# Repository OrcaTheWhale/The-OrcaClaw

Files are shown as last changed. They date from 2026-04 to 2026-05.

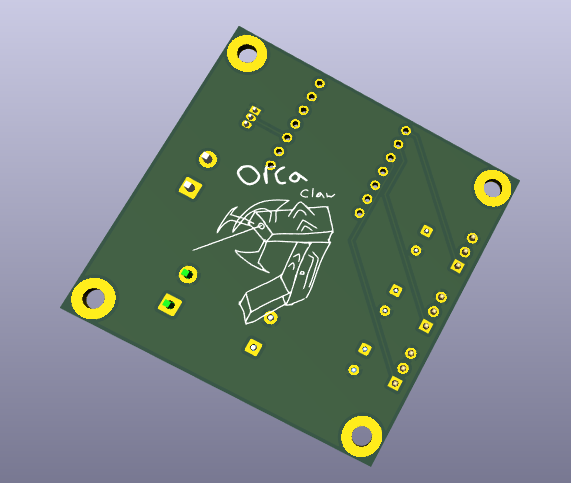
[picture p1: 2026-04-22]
assets/OrcaClawPCBBottom.png

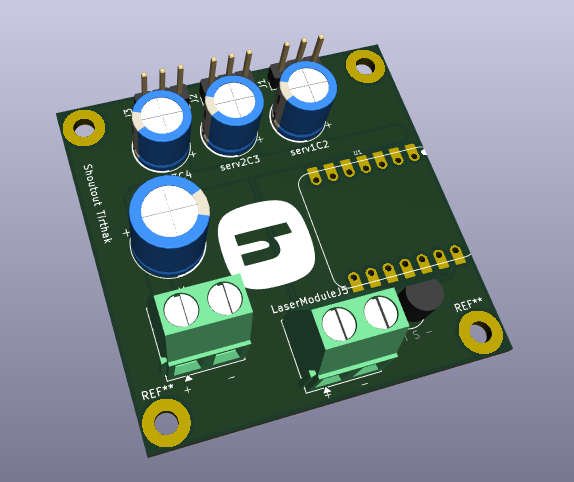
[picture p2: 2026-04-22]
assets/OrcaClawPCBTop.png

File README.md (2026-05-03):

# The-OrcaClaw
Resembling (sort of) Victor's Hexclaw from League of Legends/Arcane, the OrcaClaw is a powerful(weak) arm that can be controlled remotely, and has the ability to grab and point using a laser!

This is my first ever project outside of tinkering with a breadboard and sensors. I've never modeled, made a pcb, or know a lot about assembly(hardware components, screw types). However, after a lot of work and hours done, I was able to learn a lot, and also was able to produce this project, the OrcaClaw!

**What makes this unique**: You will never see this in the real world(cause it's kinda useless), that's just how unique it is! Resembling a Hexclaw and an Orca, the OrcaClaw is able to be able to grab _some_ items in your daily life! Whether you need to hold on to an empty soda can(for some reason), or claw menacingly at someone you don't like, the OrcaClaw, _in addition_, allows you to point at things using it's built in laser! Just like the Hexclaw, it's dangerous(if you shine it in someone's eyes, don't do that), and can ward off people who don't like light(like vampires)!

**Why I made this project**: Originally, I was going to create just a robot arm that is able to write something, with remote capabilities, like either being remote controlled or master-slave. The reason the idea pivoted was because after joining the Fallout kickoff call, I was more inspired to create something not so boring and unoriginal. An arm seemed like a perfect guide in my opinion; I will be able to make something move(neurons firing!), and learn modeling, creating PCB's, and wireless communication. I was still able to learn everything; but now the idea is much cooler! 

The OrcaClaw

Here is a list of things I learned from this project:

**Modeling**

**PCB Creation**

Assembly: 
- Different screw uses (M3 Machine Vs Thread forming, M2.6 for circuit boards)
- Onshape Assembly
- Claw Machine/Linkage style claw mechanism
- Tolerances
  
Hardware:
- Voltage step-down (Buck Converter)
- Wary of current draw (Increasing wire thickness and AWG sizes)
- Wary of current draw x2 (Capacitors for MG996R Servos)
- MOSFET gate

And more!

Here is a list of _problems_ I ran into for this project:
- WHY IS EVERYTHING EXPENSIVE
- Batteries < $20 having the battery life of a potato
- One of the batteries I bought was fine then I realized later the turtle from the tortoise and the hare race was the one delivering the product
- Buying components irl to accomodate in the design, and then realising there were cheaper options so now I have to buy those ones to stick to the BOM and source material
- Errors in OnShape
- Extrude? Hello? It's a closed area?
- Had to restart early on, not too bad though
- Screws not screwing (There's two types of screws, machine screws and thread-forming???)
- Tolerances not tolerating
- Logic errors
- Having to sacrifice a lot of rotation degrees
- Chance of the first MG996R not being able to hold up
- Trying to install the XIAO footprint (wth is git submodules and somethingEDA)
- Trying to upload the PCB to JLCPCB (literally only the holes appeared for some reason)
- AliExpress shipping lowkey being the product
- AliExpress being a master of manipulation (they removed a $20 off deal the moment I hit buy)
- One of the only good laser modules is $20 (wth)
- Slack, Fallout issues (why is fallout using a slack I never technically created?)
- Doing research at night, thinking it'd only take me a few minutes but taking me 1-2 hours I could've tracked
- Github uploading the individual files instead of the folder
- Realizing I had put two buttons on the controller pcb when I need 3 (control, claw, and laser)
- Zine page looking ahh
- Being ghosted in slack :sob: not that much tho shout out Tirthak and the gang
- AAAAAHHH

OrcaClaw 3D Model:



OrcaController 3D Model:




OrcaClaw PCB:



OrcaClaw Controller PCB:


**Wiring Diagram / Schematic:**

OrcaClaw Schematic:
OrcaClawSchematic

The OrcaClaw controller schematic is just the PCB schematic with a extra battery:
OrcaClawControllerSchematic

**How to use:** 

Attach arm and backpack straps with the clips onto the backplate. Wear it like a backpack. Congratulations! The OrcaClaw is now mounted on your back! 

On the controller, there is two buttons. One of them allow for movement control. By pressing it down and moving your arm accordingly, the accelerometer will translate that movement into the servo movement. If you move your arm left or right, it'll follow left or right. If you move your arm up or down, it'll follow your arm movement. To close/open the claw, turn the controller on the Z axis.

The other button activates the laser. Please be careful and don't shine it in someone's eyes, it will be harmful.

**Guide:**
Once accepted, a more in depth guide will be posted. For now:

Follow OnShape document for where parts go! Almost all of the parts are unique in some way; so it won't be too hard to distinguish parts in assembly.
The longer M3 thread-forming screws (4 of them) goes from the backplate --> the arm segment connecting to it. 
Everything else uses the majority M3 thread-forming screws listed in the BOM.
The components relating to the claw use the M3 machine screws with nuts to keep them in place. Do not tighten nuts to the fullest, let parts be able to rotate.

Mount components to their respective places first, and then connect the arm pieces together.
Battery: There will be a rectangle piece which you slide in after putting the battery in its case, to keep it in place.
Same with the laser, but it will be a round piece.

The PCB's and other boards use the M2.6 screws through the mounting holes.

The absolute MESS of a cad(LISTEN. THIS THE FIRST TIME I'M ACTUALLY DOING MODELING. I DIDN'T REALIZE IT WOULD LOOK THIS UNORGANIZED. PLEASE SPARE ME):
https://cad.onshape.com/documents/d7ad806e815c1aad37a0e64a/w/e4d9f00fe60cfe8595f9785c/e/b1601408fc0aed2b47a9de74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 

You may find the **BOM** here: https://github.com/OrcaTheWhale/The-OrcaClaw/blob/d58308c58e4bb3730a3b75af7c206a2e41ff7d3b/Bill%20of%20Materials.csv

You may find the **PCB Components Guide** here: https://github.com/OrcaTheWhale/The-OrcaClaw/blob/main/PCBFiles/PCB%20Components%20Guide.csv

**HEADS UP!** The BOM assumes you have a soldering iron. The prices are in CAD(Canadian money, not modeling software you nerds), and shipping prices will vary from region.
The printing legion shipping cost also may vary.

Buck Converter MAY NOT BE ACCURATE! Listing says 2 different dimensions; when I recieve it I will update the model. It also may be M3 mounting holes, and M2.6. However, the parts in the BOM have enough thread-forming screws to use M3 instead. Warning: Pilot hole will be a tight fit.

The firmware is also set in platformio! If you are using Arduino IDE, please feel free to do so.

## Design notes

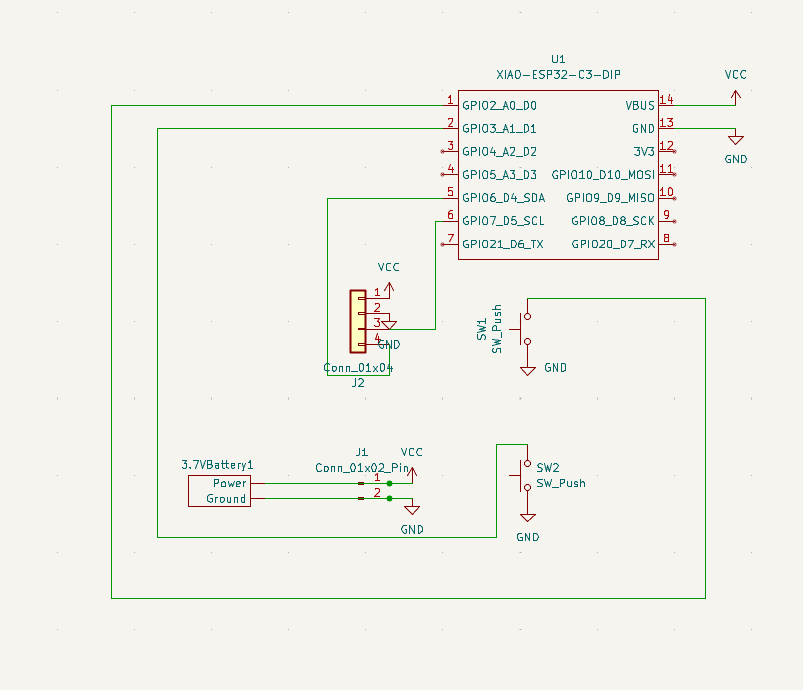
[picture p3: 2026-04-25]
assets/OrcaClawControllerSchematic.png

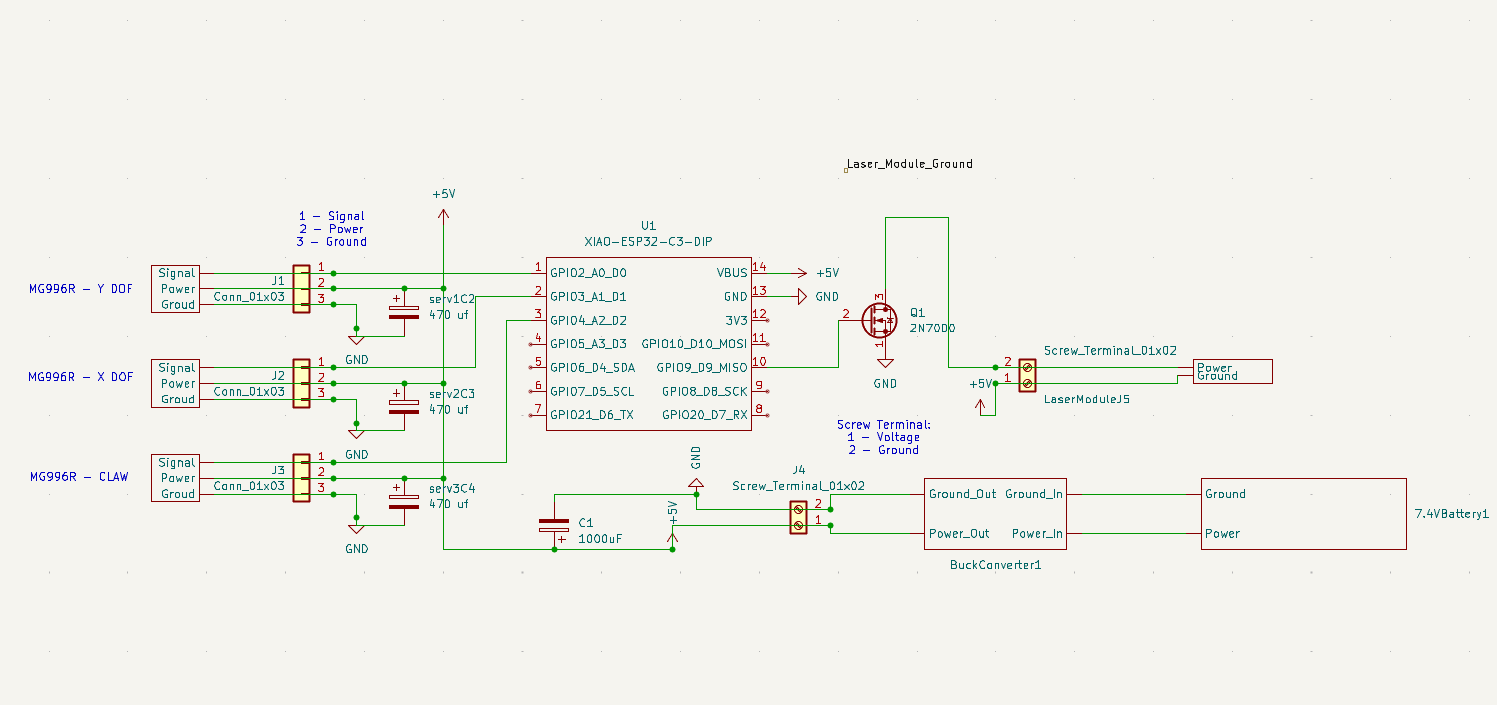
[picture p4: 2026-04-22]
assets/OrcaClawSchematic.png

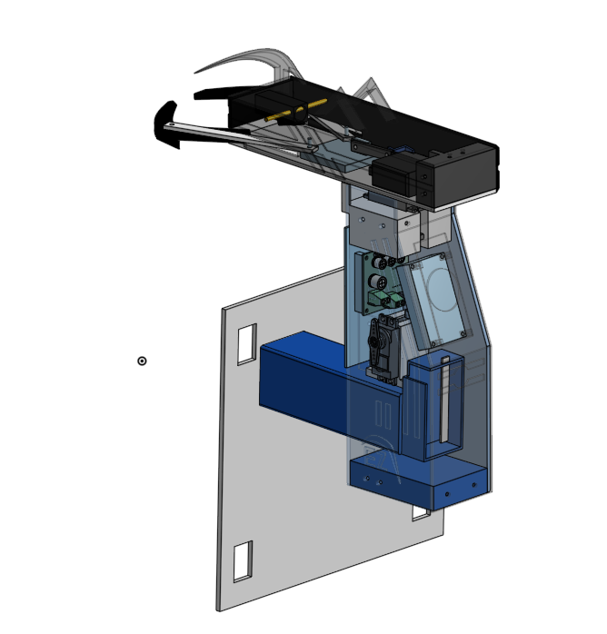
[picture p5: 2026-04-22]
assets/OrcaClawTransparentView.png

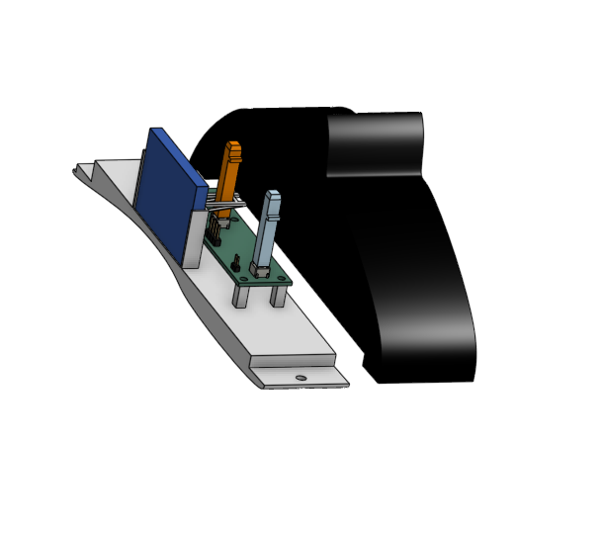
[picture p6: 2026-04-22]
assets/OrcaControllerSplitView.png

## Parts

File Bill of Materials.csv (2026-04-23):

Qty | Part Name | Price (CAD) | Shipping | Link
1 | M3 x 8 mm Machine Screw (Void)
2 | M3 x 10 mm Machine Screw (Void)
5 | M3 x 12 mm Machine Screw (Void)
8 | M3 Machine Screw Nut (Void)
1 | M3 Machine Screw Kit | $9.60 | -- | https://www.aliexpress.com/item/1005002109863123.html?curPageLogUid=AVPscaQrK0lu
12 | M2.6 x 10mm Thread Forming | $3.66 | -- | https://www.aliexpress.com/item/1005008296487858.html?curPageLogUid=paY90O6VAhlU
27 | M3 * 12mm Thread Forming | $3.08 | $3.90 | https://www.aliexpress.com/item/1005010449886696.html?curPageLogUid=hdaSnPgN5pEB
4 | M3 * 17mm Thread Forming | $4.32 | $3.90 | https://www.aliexpress.com/item/1005010449886696.html?curPageLogUid=hdaSnPgN5pEB
1 | Buck Converter 5A | $3.73 | -- | https://www.aliexpress.com/item/1005006139913551.html?curPageLogUid=A9hs5zlVt0rK
3 | MG996R Servo | $20.01 | -- | https://www.aliexpress.com/item/1005006319164742.html?curPageLogUid=5URVzNdkgF8G
3 | 10V 470uf Capacitor | $4.02 | -- | https://www.aliexpress.com/item/1005005920255833.html?curPageLogUid=eVIktV37r9gq
1 | 16V 1000uf Capacitor | $5.21 | -- | https://www.aliexpress.com/item/1005005920255833.html?curPageLogUid=eVIktV37r9gq
13 | Pin Header 2.54 mm Pitch Vertical | $3.60 | -- | https://www.aliexpress.com/item/1005005241876888.html?curPageLogUid=Aj35UNej6cp6
2 | Pin Header 2.0 mm Pitch Vertical | $0.75 | $7.59 | https://www.aliexpress.com/item/1005009312765794.html?curPageLogUid=4RsGl9YfAJN6
2 | Screw Terminal 5.08mm Pitch | $3.71 | $6.64 | https://www.aliexpress.com/item/1005008305755665.html?curPageLogUid=pvGs9VTbT28r
1 | TO-92 Mosfet | $3.53 | -- | https://www.aliexpress.com/item/32966284825.html?curPageLogUid=V1YsM17IT08L
1 | T-Blade Adapter Female | $4.94 | -- | https://www.aliexpress.com/item/1005009579735259.html
1 (Optional) | Focusable 450nm 50mw Laser Module | $12.11 | $9.69 | https://www.aliexpress.com/item/1005010403717946.html
1 | 22AWG Wire 1 meter | $2.45 | -- | https://www.aliexpress.com/item/1005008563402600.html
1 | Gy-521 Module | $3.14 | -- | https://www.aliexpress.com/item/1005008796700745.html?curPageLogUid=8ee2Z7oAXeiP
1 | 7.4V Li-ion Battery 2000mAh | $29.49 | -- | https://www.amazon.ca/dp/B0CHMFN7KN?ref=ppx_yo2ov_dt_b_fed_asin_title&th=1
1 | 3.7V Li-ion Battery 1100mAh | $18.79 | -- | https://www.amazon.ca/dp/B08FD39Y5R?ref=ppx_yo2ov_dt_b_fed_asin_title&th=1
2 | Push Button | $3.42 | -- | https://www.aliexpress.com/item/1005002487399422.html?curPageLogUid=LvFZBIjikn2H
2 | XIAO Esp-32 C3 | $25.56 | -- | https://www.aliexpress.com/item/1005004723068527.html
1 | Backpack straps | $18.99 | -- | https://www.amazon.ca/dp/B0FKGX4SWJ?ref=ppx_yo2ov_dt_b_fed_asin_title&th=1
 | 3D Print Models - Printing Legion |  | $5.00
1 | OrcaClaw Arm PCB (JLCPCB) | $9.40 | $1.02
1 | OrcaClaw Controller PCB (JLCPCB) | $5.58 | $1.02
1 | Tax | 25.92
 | COST: | $225.01 | $38.76
 | TOTAL COST: | $263.77 | (´。＿。｀)

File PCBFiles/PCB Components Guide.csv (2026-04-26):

Component Name | REF on PCB
OrcaClaw PCB
1x03 Pin Headers 2.54mm Pitch | J1, J2, J3
470uF Capacitors | serv1C2, serv2C3, serv3C4
1000uF Capacitor | C1
Screw Terminal 5.08mm Pitch | J4, LaserModule J5
MOSFET | Q1
OrcaClaw Controller PCB
1x04 Pin Headers 2.54mm Pitch | J2
1x02 Pin Headers 2.00mm Pitch | J1
Push Buttons | SW1, SW2

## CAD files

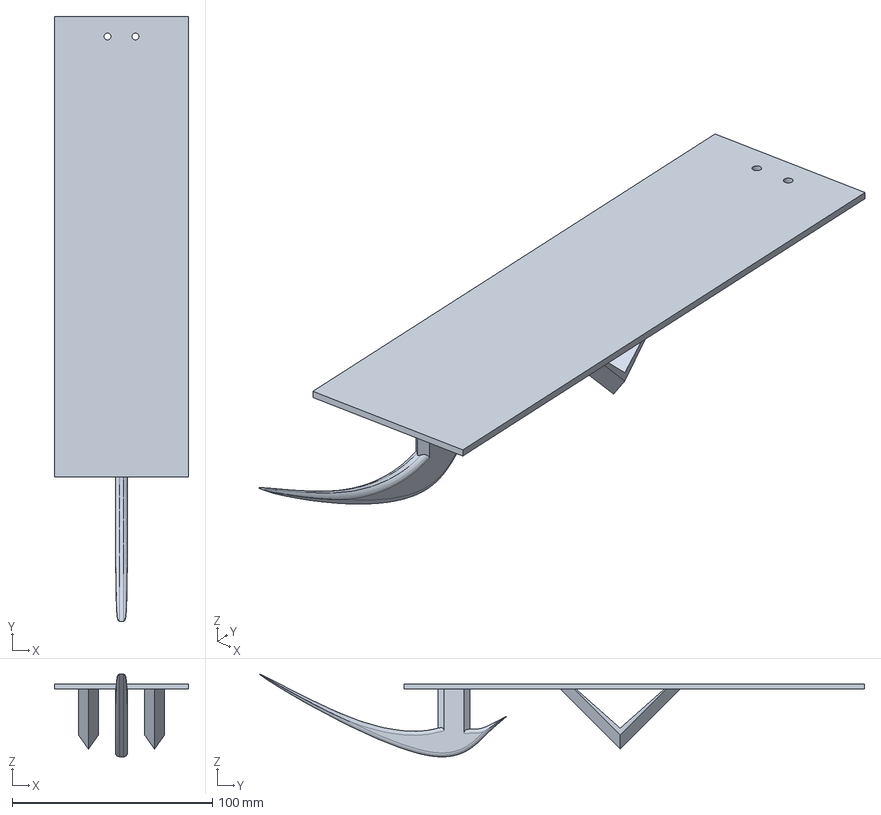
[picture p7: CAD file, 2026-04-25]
StepFiles/Arm Parts/Arm Parts - XRoof.step
67.0 x 302.1 x 41.3 mm

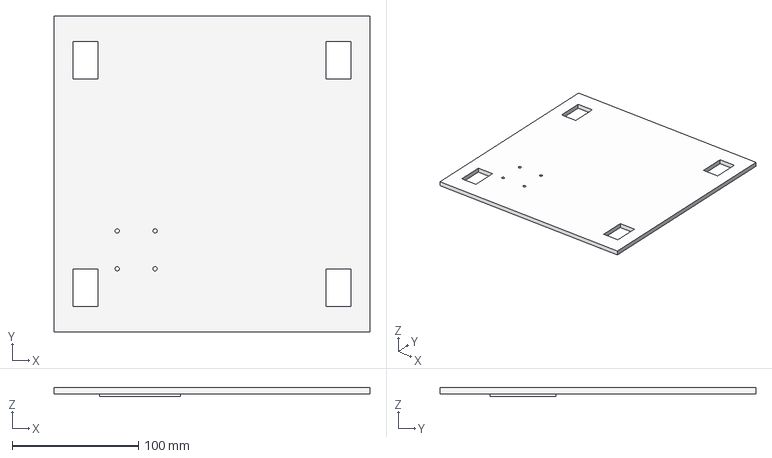
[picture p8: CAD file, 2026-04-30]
StepFiles/BackplateSegment/Backplate.step
250.0 x 250.0 x 7.00 mm

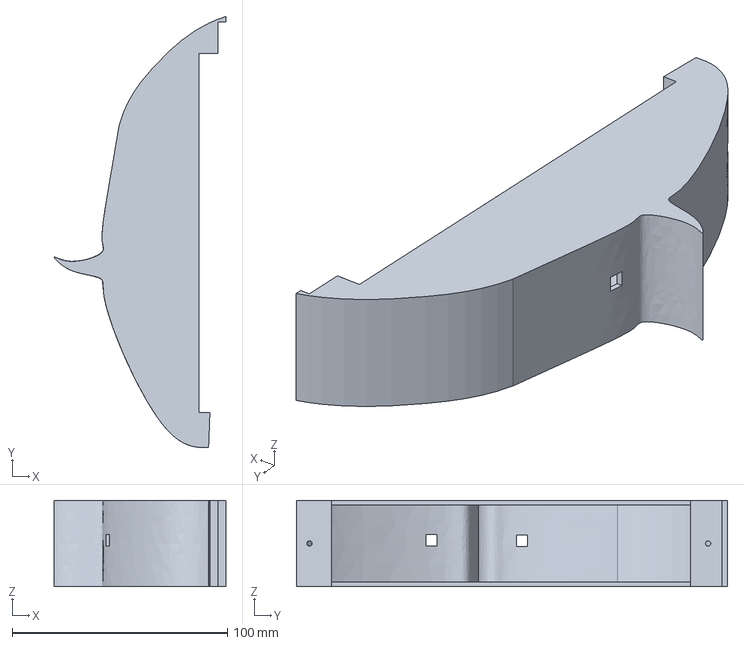
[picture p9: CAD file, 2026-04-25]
StepFiles/Controller/Controller - Top.step
79.8 x 200.4 x 40.0 mm

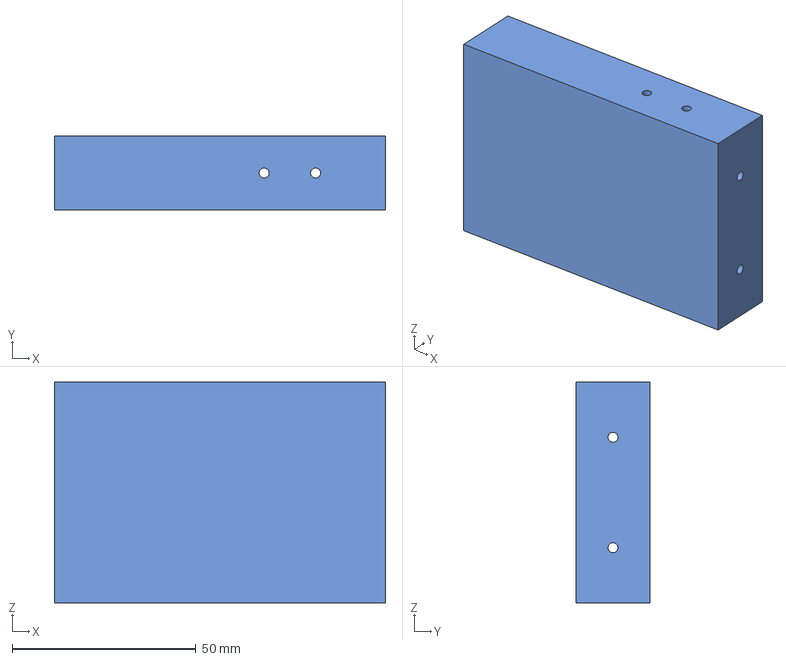
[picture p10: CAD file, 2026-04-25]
StepFiles/Arm Parts/Arm Parts - ArmConnector1.step
90.0 x 20.0 x 60.0 mm

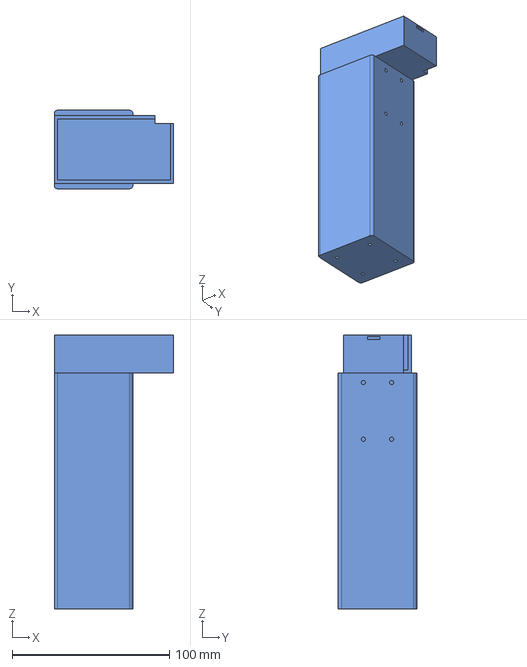
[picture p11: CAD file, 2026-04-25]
StepFiles/BackplateSegment/Electronics-Components - FirstArmSegment+BatteryCase.step
76.0 x 50.0 x 174.3 mm

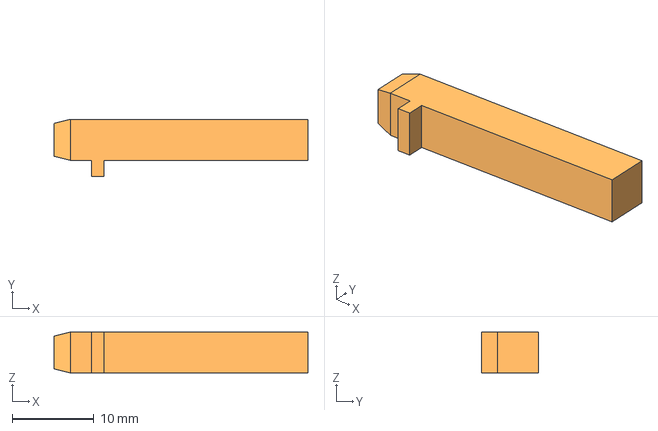
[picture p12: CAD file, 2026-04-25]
StepFiles/Controller/Controller - Button2.step
31.0 x 7.00 x 5.00 mm

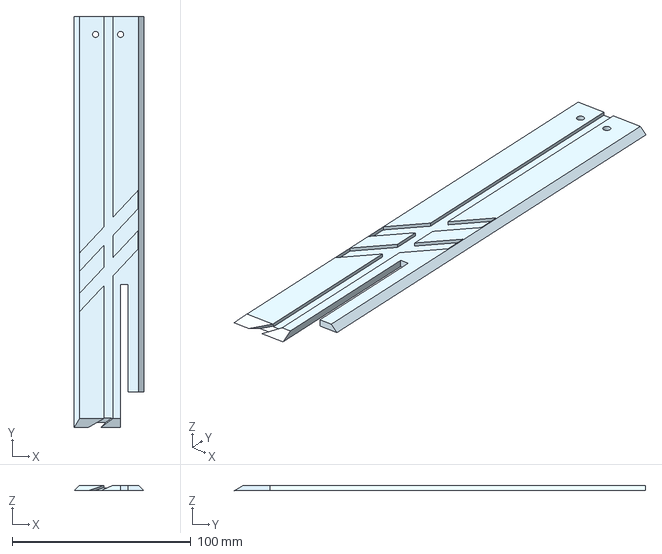
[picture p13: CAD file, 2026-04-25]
StepFiles/Arm Parts/Arm Parts - XWall2.step
39.0 x 230.0 x 3.00 mm

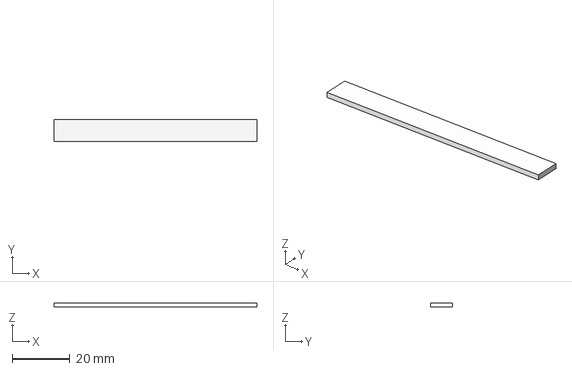
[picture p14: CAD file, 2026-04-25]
StepFiles/BackplateSegment/Electronics-Components - Part 13.step
70.0 x 7.50 x 1.50 mm

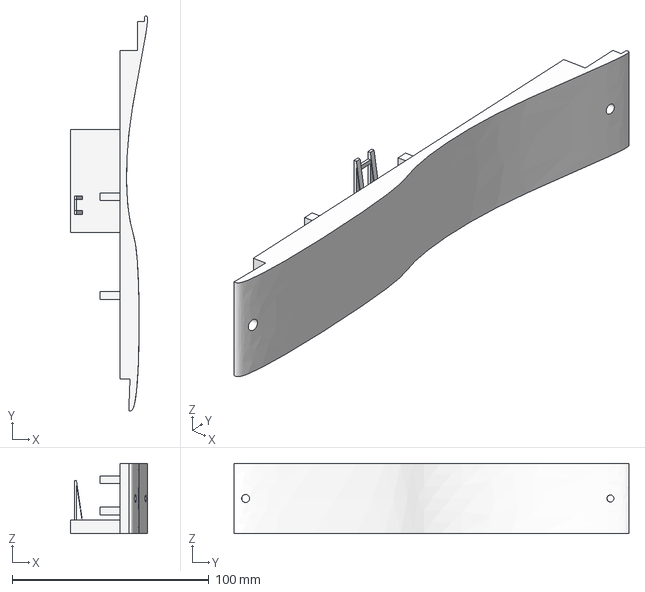
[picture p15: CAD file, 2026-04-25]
StepFiles/Controller/Controller - Bottom.step
39.1 x 200.6 x 35.8 mm

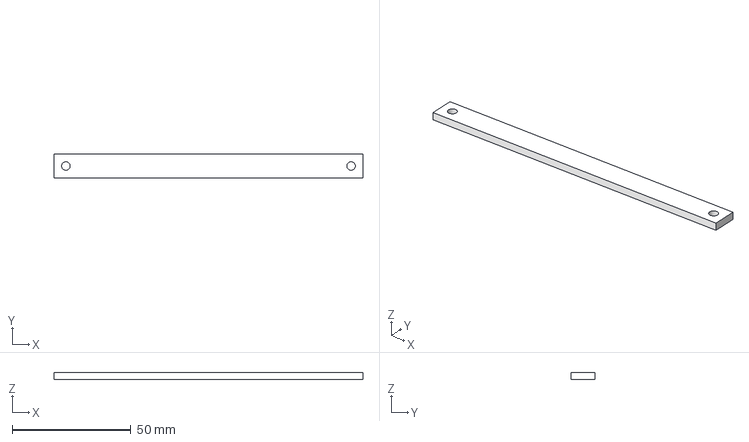
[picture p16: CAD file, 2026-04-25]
StepFiles/Arm Parts/Arm Parts - Link.step
130.0 x 10.0 x 3.00 mm

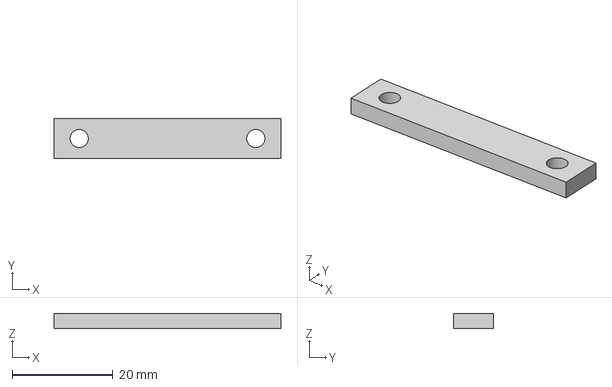
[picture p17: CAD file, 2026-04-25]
StepFiles/Arm Parts/Arm Parts - SliderLink.step
45.0 x 8.00 x 3.00 mm

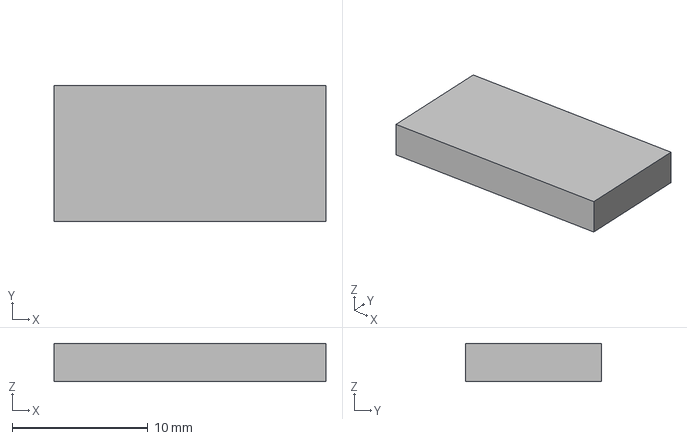
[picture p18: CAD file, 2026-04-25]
StepFiles/Arm Parts/Arm Parts - Connecter.step
20.0 x 10.0 x 2.80 mm

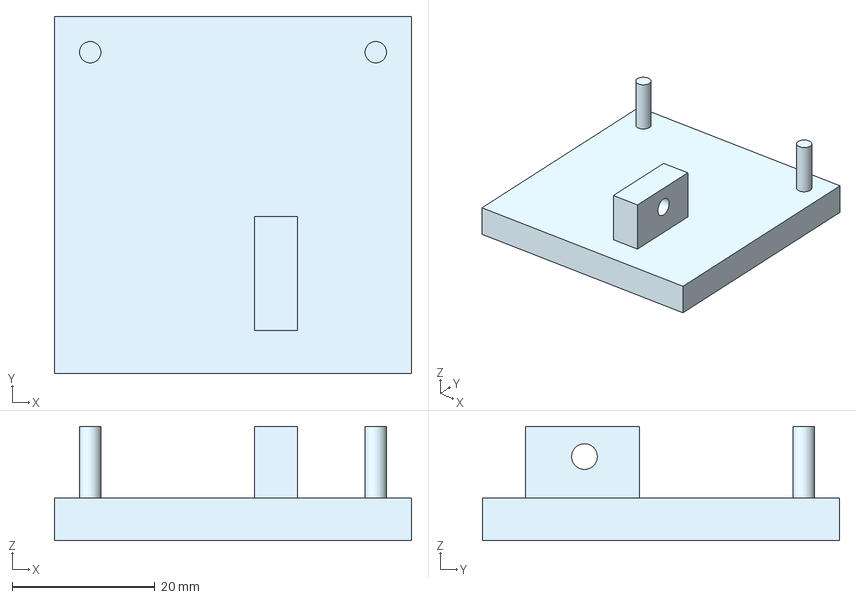
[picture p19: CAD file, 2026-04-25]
StepFiles/Arm Parts/Arm Parts - Slider.step
50.0 x 50.0 x 16.0 mm

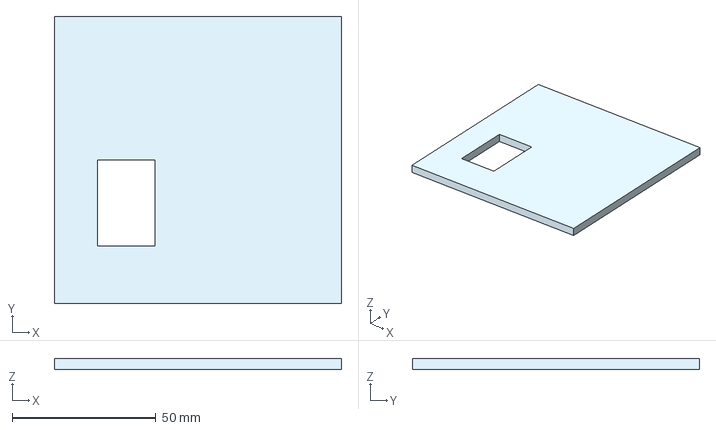
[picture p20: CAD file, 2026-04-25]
StepFiles/Arm Parts/Arm Parts - PlateTest.step
100.0 x 100.0 x 4.00 mm

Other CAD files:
StepFiles/Controller/Controller - Button1.step
StepFiles/Arm Parts/Arm Parts - Dof2.step
StepFiles/Arm Parts/Arm Parts - Arm1(Other Side).step
StepFiles/Arm Parts/Arm Parts - Claw2.step
StepFiles/Arm Parts/Arm Parts - Arm1.step
StepFiles/Arm Parts/Arm Parts - Arm2(Other Side).step
StepFiles/Arm Parts/Arm Parts - ArmLayer1.step
StepFiles/Arm Parts/Arm Parts - Claw1.step
StepFiles/Arm Parts/Arm Parts - Dof1-.step
StepFiles/Arm Parts/Arm Parts - LaserBarrier.step
StepFiles/Arm Parts/Arm Parts - Link(2).step
StepFiles/Arm Parts/Arm Parts - ServoLink.step
StepFiles/Arm Parts/Arm Parts - Shell1.step
StepFiles/Arm Parts/Arm Parts - XConnector.step
StepFiles/Arm Parts/Arm Parts - XFloor.step
StepFiles/Arm Parts/Arm Parts - XWall.step
StepFiles/Arm Parts/Arm Parts - YCoverWall.step

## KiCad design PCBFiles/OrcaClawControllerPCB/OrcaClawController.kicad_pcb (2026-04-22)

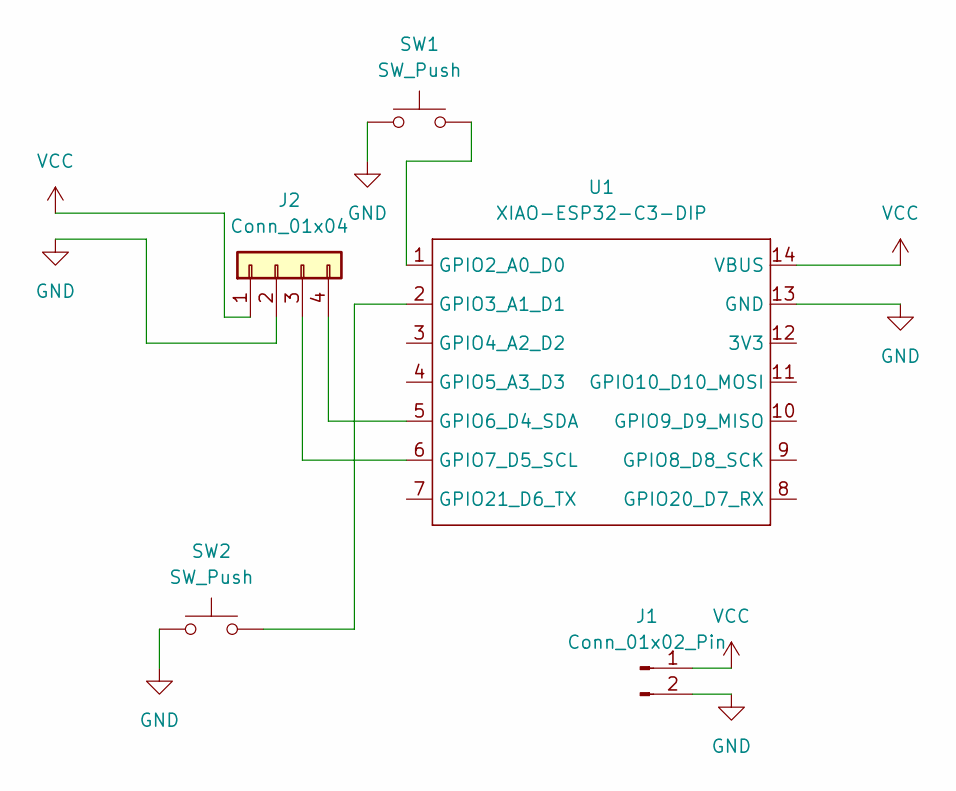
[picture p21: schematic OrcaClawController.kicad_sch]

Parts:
J1: Conn_01x02_Pin; PinHeader_1x02_P2.00mm_Vertical
J2: Conn_01x04; PinHeader_1x04_P2.54mm_Vertical
SW1, SW2: SW_Push; SW_PUSH_6mm
U1: XIAO-ESP32-C3-DIP

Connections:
GND: J1.2, J2.2, SW1.1, SW2.1, U1.13 (GND)
unnamed: J2.3, U1.6 (GPIO7_D5_SCL)
unnamed: J2.4, U1.5 (GPIO6_D4_SDA)
unnamed: SW1.2, U1.1 (GPIO2_A0_D0)
unnamed: SW2.2, U1.2 (GPIO3_A1_D1)
VCC: J1.1, J2.1, U1.14 (VBUS)

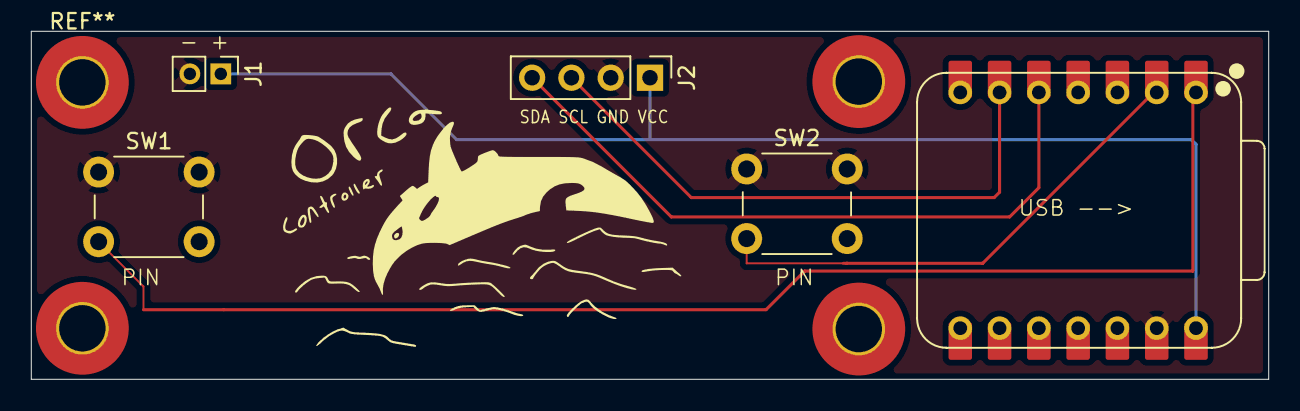
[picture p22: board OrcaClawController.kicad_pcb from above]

Board: 4 copper layers, 80.0 x 22.5 mm, 5 parts (0 on the bottom side), 6 nets.

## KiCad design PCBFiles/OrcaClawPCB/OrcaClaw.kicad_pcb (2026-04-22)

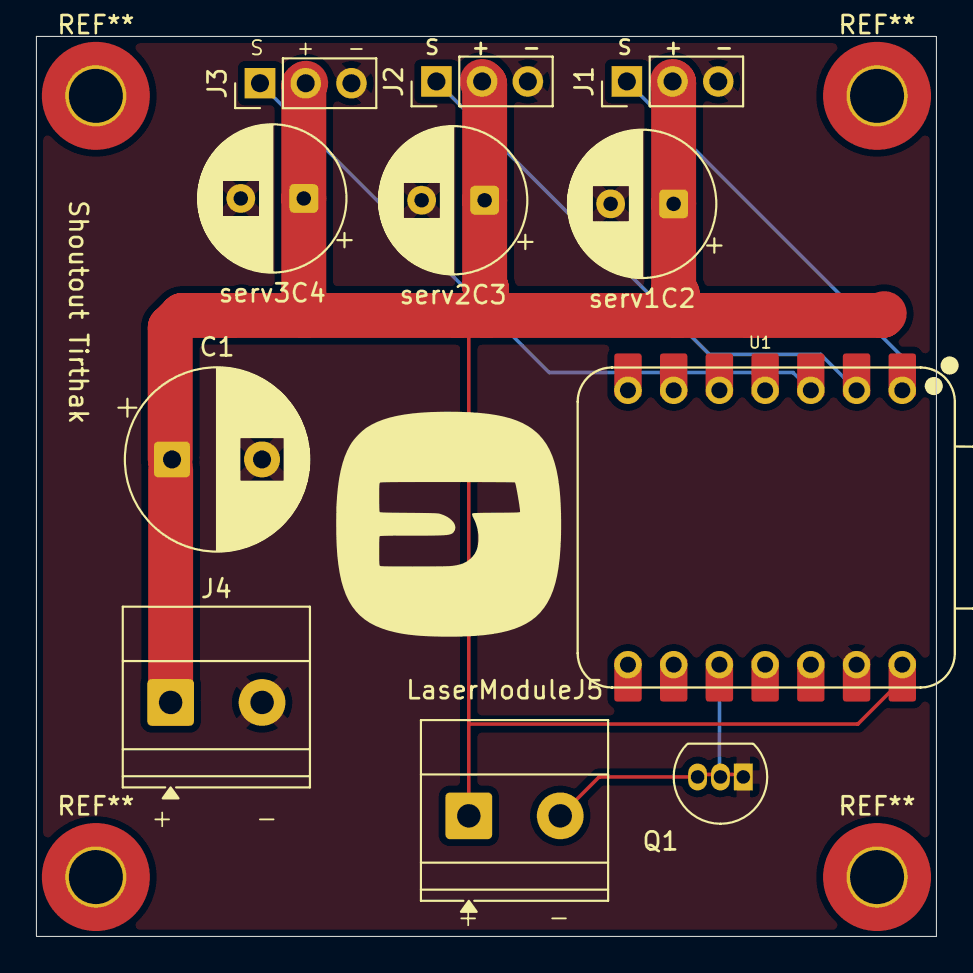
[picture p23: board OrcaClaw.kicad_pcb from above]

Board: 4 copper layers, 50.0 x 50.0 mm, 12 parts (0 on the bottom side), 7 nets.

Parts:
.: LOGO
C1: 1000uF 10V; CP_Radial_D10.0mm_P5.00mm
J1, J2, J3: Conn_01x03; PinHeader_1x03_P2.54mm_Vertical
J4: Screw_Terminal_01x02; TerminalBlock_Phoenix_MKDS-1,5-2-5.08_1x02_P5.08mm_Horizont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
LaserModuleJ5: Screw_Terminal_01x02; TerminalBlock_Phoenix_MKDS-1,5-2-5.08_1x02_P5.08mm_Horizont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
Q1: 2N7000; TO-92_Inline
U1: XIAO-ESP32-C3-DIP
serv1C2, serv2C3, serv3C4: 470 uf; CP_Radial_D8.0mm_P3.50mm

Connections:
+5V: C1.1, J1.2, J2.2, J3.2, J4.1, LaserModuleJ5.1, U1.14 (VBUS), serv1C2.1, serv2C3.1, serv3C4.1
GND: C1.2, J1.3, J2.3, J3.3, J4.2, Q1.1 (S), U1.13 (GND), serv1C2.2, serv2C3.2, serv3C4.2
unnamed: J1.1, U1.1 (GPIO2_A0_D0)
unnamed: J2.1, U1.2 (GPIO3_A1_D1)
unnamed: J3.1, U1.3 (GPIO4_A2_D2)
unnamed: LaserModuleJ5.2, Q1.3 (D)
unnamed: Q1.2 (G), U1.10 (GPIO9_D9_MISO)

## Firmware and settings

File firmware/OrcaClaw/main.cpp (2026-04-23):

#include <Arduino.h>
#include <esp_now.h>
#include <WiFi.h>
#include <Wire.h>
#include <ESP32Servo.h>

const int ydof = 2;
const int xdof = 3;
const int clawpin = 4;
const int laser = 9;


Servo ServoX;
Servo ServoY;
Servo Claw;


int accelx, accely, homex, homey, gyroz;
// degrees of freedom for y, and x

int xmaximum = 160; // max degrees of freedom for x, can be changed after testing
int xminimum = 0;
int xdegree = 80;

int yminimum = 60;
int ymaximum = 115; // <-- IMPORTANT TO CHANGE THIS TO REDUCE STALL
int ydegree = 70;

int servostep = 5; // degrees to move per loop, can be changed after testing

int clawopen = 0;
int clawclosed = 60;

bool clawstate = false;

typedef struct {
  bool contact;
  int x;
  int y;
  int homex;
  int homey;
  int homegyroz;
  bool laser;
  int gyroz;
  
  bool claw;
} Payload;

Payload incoming;

void onReceive(const uint8_t *mac_addr, const uint8_t *data, int data_len) {
  
  memcpy(&incoming, data, sizeof(incoming));

  // Variables setup
  // Check if contact. New data wouldn't send anyways;
  if (incoming.contact) {
    accelx = incoming.x;
    accely = incoming.y;
    homex = incoming.homex;
    homey = incoming.homey;
    gyroz = incoming.gyroz;
    clawstate = incoming.claw;
    if (incoming.laser) {
      digitalWrite(laser, HIGH);
    } else {
      digitalWrite(laser, LOW);
    }
    if (accelx < homex + 300) { //300 is the threshold for movement, can be changed after testing
      if (xdegree > xminimum) {
        xdegree -= servostep; 
        ServoX.write(xdegree);
      }
    } else if (accelx > homex - 300) {
      if (xdegree < xmaximum) {
        xdegree += servostep;
        ServoX.write(xdegree);
      }
    }
    if (accely > homey + 300) {
      if (ydegree < ymaximum) {
        ydegree += servostep;
        ServoY.write(ydegree);
      }
    // raise arm
    } else if (accely < homey - 300) {
      if (ydegree > yminimum) {
        ydegree -= servostep;
        ServoY.write(ydegree);
      }
    // lower arm
    }

    //Open / close claw
    if (gyroz > incoming.homegyroz + 300) {
      if (clawstate) {
        Claw.write(clawopen);
        clawstate = true;
      } else if (gyroz <= incoming.homegyroz) {
        Claw.write(clawclosed);
        clawstate = false;
      } 
      
    }
  
}

  
  

  //Pseudocode
  // receive x, y from gy-521
  // store first recieved x and y after button pressed as "home" position
  // if x < left of home position, turn left
  // if x > right of home position, turn right
  // if y > home position, raise arm
  // if y < home position, lower arm
  
  //track degree. If degree of freedom is greater than threshold, do not allow movement (preventing high current pull from stall)
  //

  //button 2 recieve, open / close claw
  
/*
  Serial.print("(Signature: Edward) Received: ");
  Serial.print(incoming.x);
  Serial.print(", ");
  Serial.println(incoming.y);
  */
}


void setup() {
  // put your setup code here, to run once:
  Serial.begin(115200);
  WiFi.mode(WIFI_STA);


  if (esp_now_init() != ESP_OK) {
    Serial.println("Error initializing ESP-NOW");
    return;
  }

  ServoX.attach(xdof);
  ServoY.attach(ydof);
  Claw.attach(clawpin);

  pinMode(laser, OUTPUT);

  ServoX.write(xdegree);
  ServoY.write(ydegree);
  Claw.write(clawopen);
 // Allow jitter for the capacitors
  delay(100);
  ServoX.write(xdegree+50);
  ServoY.write(ydegree+50);
  Claw.write(clawclosed);
  delay(100);
  ServoX.write(xdegree);
  ServoY.write(ydegree);
  Claw.write(clawopen);
  //reset position and jitter to allow capacitors to do their thing
  

esp_now_register_recv_cb(onReceive);

}

void loop() {
  // put your main code here, to run repeatedly:
}

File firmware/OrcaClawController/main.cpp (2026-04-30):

#include <Arduino.h>
#include <esp_now.h>
#include <WiFi.h>
#include <Wire.h>

const int MPU_ADDR=0x68; // I2C address of the MPU-6050

int16_t accel_x, accel_y, gyroz;
 

const int control = 2;
const int laser = 3;
const int sda = 6;
const int scl = 7;



bool bounced;
bool laserbounce = false;


uint8_t receiverMAC[] = {0xA4, 0xF0, 0x0F, 0x61, 0xF4, 0x10}; // YOUR OTHER ESP WIFI CODE HERE

typedef struct {
  bool contact;
  int x;
  int y;
  int homex;
  int homey;
  int gyroz;
  int homegyroz;
  bool laser;
  bool claw;
} Payload;
Payload data;


void onSent(const uint8_t *mac_addr, esp_now_send_status_t status) {
  Serial.print("Send Status: ");
  Serial.println(status == ESP_NOW_SEND_SUCCESS ? "Delivery Success" : "Delivery Fail");
}

void setup() {
  // put your setup code here, to run once:
  Serial.begin(115200);
  //pinMode(led, OUTPUT);
  delay(1000);
  //Getting WIFI Setup
  WiFi.mode(WIFI_STA);
  Serial.println(WiFi.macAddress());
  if (esp_now_init() != ESP_OK) {
    Serial.println("Error initializing ESP-NOW");
    return;
  }
  esp_now_register_send_cb(onSent);
  esp_now_peer_info_t peerInfo = {};
  memcpy(peerInfo.peer_addr, receiverMAC, 6);
  peerInfo.channel = 0;
  peerInfo.encrypt = false;

  esp_now_add_peer(&peerInfo);

  //reset position and jitter to allow capacitors to do their thing
  //claw position = false

  //claw position: false = closed, true = open
  pinMode(control, INPUT_PULLUP);
  pinMode(laser, INPUT_PULLUP);

  Wire.begin();
  Wire.beginTransmission(MPU_ADDR);
  Wire.write(0x6B); // PWR_MGMT_1 register
  Wire.write(0);    // set to zero (wakes up the MPU-605
  Wire.endTransmission(true);
  laserbounce = false;

}

void loop() {
  // put your main code here, to run repeatedly:
  //data.led = random(0, 3);

  // No idea what is this but it gets gy-521 data

  Wire.beginTransmission(MPU_ADDR);
  Wire.write(0x3B); // starting with register 0x3B (ACCEL_XOUT_H)
  Wire.endTransmission(false);
  Wire.requestFrom(MPU_ADDR, 14, true); // 
  
  
  accel_x = Wire.read() << 8 | Wire.read();
  accel_y = Wire.read() << 8 | Wire.read();

  for (int i = 0; i < 8; i++) {
    Wire.read();
  }

  gyroz = Wire.read() << 8 | Wire.read();
  

// Psuedocode
// detect if button is pressed, if not ignore
// data.x = gy-521 x
// data.y = gy-521 y
// if claw button pressed, check if true/false then flip value and send
  data.x = accel_x;
  data.y = accel_y;
  data.gyroz = gyroz;

  //Set a home position
  if (digitalRead(control) == LOW && !bounced) {
    data.homex = accel_x;
    data.homey = accel_y;
    data.gyroz = gyroz;
    data.homegyroz = gyroz;
    bounced = true;
    data.contact = true;
  } else if (digitalRead(control) == HIGH) {
    data.contact = false;
    bounced = false;
  }

  if (digitalRead(laser) == LOW && !laserbounce) {
    data.laser = !data.laser;
    laserbounce = true;
  } else if (digitalRead(laser) == HIGH) {
    laserbounce = false;
  }
  
  esp_err_t result = esp_now_send(receiverMAC, (uint8_t *)&data, sizeof(data));
  delay(1000);
  
}
